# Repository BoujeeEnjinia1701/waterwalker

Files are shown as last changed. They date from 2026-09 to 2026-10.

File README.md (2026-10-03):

# WaterWalker

     

**Area:** Mobility and Logistics · **TRL:** 3 of 9 (proof of concept on paper) · **Value-engineering target:** USD 450 (estimated USD 492) · **Difficulty:** 3 of 5

Four-wheel walk-inside water carrier. The user walks between large wheels, rollator style, pushing through a hip bar, while a low padded cradle holds four 20 L jerrycans or two clay pots between the axles. Mounting points for a later push-sensing hub motor assist for sand and slopes.

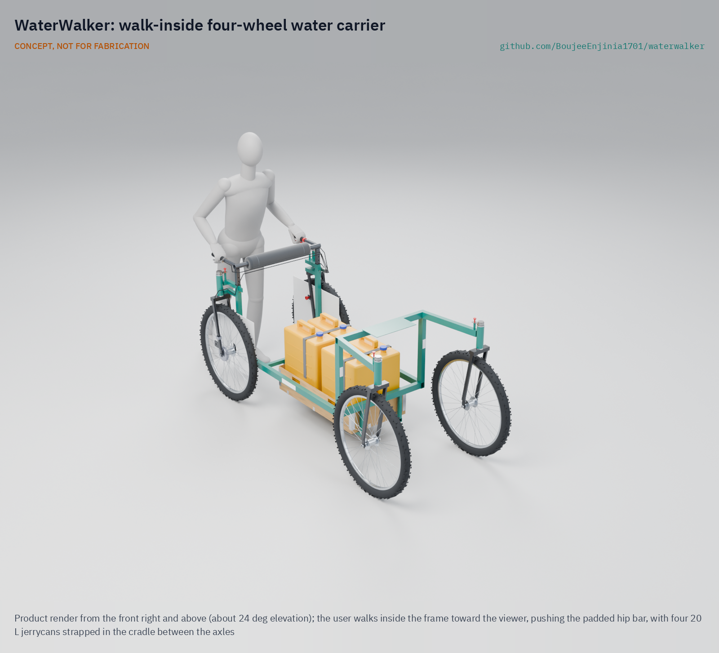
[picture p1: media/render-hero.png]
WaterWalker: walk-inside four-wheel water carrier, product render


[Exploded render](media/render-exploded.png) · [Detail render](media/render-detail.png) · [Interactive 3D model](media/viewer.html) · [Concept blueprint (PDF)](media/concept-blueprint.pdf) · [General arrangement WWK-DWG-001 (PDF)](cad/drawings/WWK-DWG-001.pdf) · [Sizing calculations WWK-CAL-001](docs/04-calcs/01-sizing.md) · [Prototype build plan WWK-BLD-001](docs/05-build-plan.md) · [Design decisions register WWK-DEC-001](docs/06-design-decisions.md) · [Review note](docs/REVIEW.md)

## Concept rationale

Wheels move water far better than heads do, but the rolling drums and carts already in use struggle on sand, on slopes and in tight turns, and a one-wheeled barrow asks for lifting and balance. WaterWalker puts the user inside a four-wheeled frame, the way a rollator does, so she walks normally, pushes with her hips as well as her hands, and steers by turning her body. The load rides low between the axles, where it cannot tip onto her or strain her neck, and the carrier works with the 20 L jerrycans households already own.

The design is open (CERN-OHL-S) and garage-buildable because the people who would use it live far from any factory. Everything is mild steel tube that a village welder can cut and repair, plus standard 26 in bicycle wheels, forks, cables and drum hubs sold in rural markets. An open design lets a local partner change the cradle, the width or the brakes after co-design sessions without asking anyone's permission, and lets repairs happen where the carrier breaks.

## Burning platform

According to the [WHO](https://www.who.int/news-room/fact-sheets/detail/drinking-water), 2.2 billion people still lacked safely managed drinking water services in 2022. Where water is not piped to the home, the carrying falls mostly on women: the 2023 WHO/UNICEF Joint Monitoring Programme report found that women and girls are primarily responsible for water collection in [7 out of 10 households](https://www.unicef.org/press-releases/women-and-girls-bear-brunt-water-and-sanitation-crisis-new-unicef-who-report) without water on the premises, and that 1.8 billion people live in such households.

The time lost is vast. [UNICEF estimates](https://www.unicef.org/press-releases/unicef-collecting-water-often-colossal-waste-time-women-and-girls) that women and girls spend 200 million hours every day collecting water, time taken from school, paid work and rest. Each head-carried trip moves a single 20 L container, about 20 kg.

## Where it could be used

### By industry

| Industry | Use |
| --- | --- |
| Rural water supply and WASH programmes | Last-mile carriage from boreholes, tap stands and water kiosks to homes, alongside new water points |
| Humanitarian response and refugee settlements | Moving water from distribution points to shelters over sandy or unpaved ground |
| Disaster response and civil protection | Carrying water from tanker trucks and supply points to homes while piped supply is cut |
| Smallholder farming | Watering seedlings and kitchen gardens, and moving produce or feed on footpaths |
| Schools and health posts without piped water | Bringing enough water for drinking, cooking and handwashing in fewer trips |

### By country or region

| Country or region | Why it matters there |
| --- | --- |
| Ethiopia | Only [49.6 % of people have basic water supply](https://www.unicef.org/ethiopia/water-sanitation-and-hygiene-wash), so many households walk to a water point on dirt paths in highlands and lowlands |
| Niger | [Only 56 % of the population has access to a source of drinking water](https://www.unicef.org/niger/water-sanitation-and-hygiene), so the rest must carry water from a source farther away |
| India | [Close to 54 % of rural women spend an estimated 35 minutes getting water every day](https://www.unicef.org/india/what-we-do/clean-drinking-water), equivalent to 27 days' lost wages a year, and less than 49 % of rural people use safely managed drinking water |
| Peru (hillside settlements of peri-urban Lima) | About 350 tanker trucks a day supply some 250,000 homes on the outskirts of Lima, and [a hillside household gets about 1,100 L of water a month](https://www.sciencedirect.com/science/article/pii/S2667010025003051) from tanks and trucks rather than household taps; on steep paths the brake, parking lock and slope limits matter |
| Japan (Noto Peninsula) | The January 2024 Noto earthquake [left up to 135,000 households without running water](https://www.japantimes.co.jp/news/2024/02/23/japan/society/noto-quake-sparks-water-debate/), and nearly 24,000 homes in Ishikawa Prefecture were still without water seven weeks later |

## What sparked the idea

The idea traces back to the rollator, the four-wheeled walking frame whose prototype the Swedish inventor Aina Wifalk designed in 1978 while working at an orthopedic clinic in Västerås, after polio had limited her own mobility ([Swedish Institute](https://sharingsweden.se/materials/the-invention-of-the-walker)). She never patented it, so that it could reach as many people as possible ([Svenskt UppfinnareMuseum](https://svensktuppfinnaremuseum.se/aina-wifalk/)), and today people of almost any age walk inside one without training. WaterWalker borrows that stance, walking inside a wheeled frame and pushing with the body, and her open approach, and applies both to the 20 L jerrycan instead of a person's own weight.

## Problem

Women and girls in rural sub-Saharan Africa and other low-income regions walk long distances carrying about 20 L of water on their heads per trip, which limits the quantity collected and causes neck and spine injuries. Design with, not for: requirements must come from co-design sessions and field trials with the intended users through a local partner.

## Concept

Four-wheel walk-inside water carrier. The user walks between large wheels, rollator style, pushing through a hip bar, while a low padded cradle holds four 20 L jerrycans or two clay pots between the axles. Mounting points for a later push-sensing hub motor assist for sand and slopes.

At TRL 3 the design is constructable: every part can be cut, welded, bought and fitted, and the build plan (WWK-BLD-001) shows how. Making it buildable added a cradle carrier, two-level rear head tube brackets, headsets and steering locks at all four forks and the fixings the concept lacked (WWK-DDR-003, accepted by Amish on 2026-10-02). His decisions of that day added a hold-to-release brake (let go of the bail under the left grip and a spring applies both rear brakes), a torque-arm tab on each rear fork for a two-motor assist kit, rated load and slope plates and hand holds in the cradle walls, which raised the empty mass to 40.3 kg. The sizing calculations (WWK-CAL-001 v0.4) show the carrier turns in 3.7 m and lifts containers only 364 mm, but four requirements are not met on paper: firm-path push (61.2 N against 60 N), loose sand (241 to 367 N against 150 N), the 10 % climb (182.6 N against 180 N) and empty mass (40.3 kg against 35 kg). The first prototype has no assist but keeps mounting points for a kit built to SwapCell interface v0.3, and parks with a positive lock pin. Value-engineering target: USD 450. Estimated cost of the constructable design: USD 492 (USD 42 over the target).

Full design precis: [docs/02-concept.md](docs/02-concept.md)

## Key components

- Welded mild steel tube frame with a cradle carrier and assist mounting points
- 26 in bicycle wheels in rigid forks on headsets, with puncture-resistant tires (4); front forks swivel and pin straight, rear forks are pinned straight
- Hip and hand push bar
- Padded plywood cradle for four jerrycans or two clay pots, bolted to two steel bearers
- Rear drum brakes with a lever latch for short stops, a hold-to-release brake and a parking lock pin
- Later, optional: two 250 W, 48 V hub motors with push-force sensor
- Later, optional: SwapCell pack (interface v0.3) in a class V1 receiver

The working bill of materials is in [bom/bom.csv](bom/bom.csv).

## Building the prototype

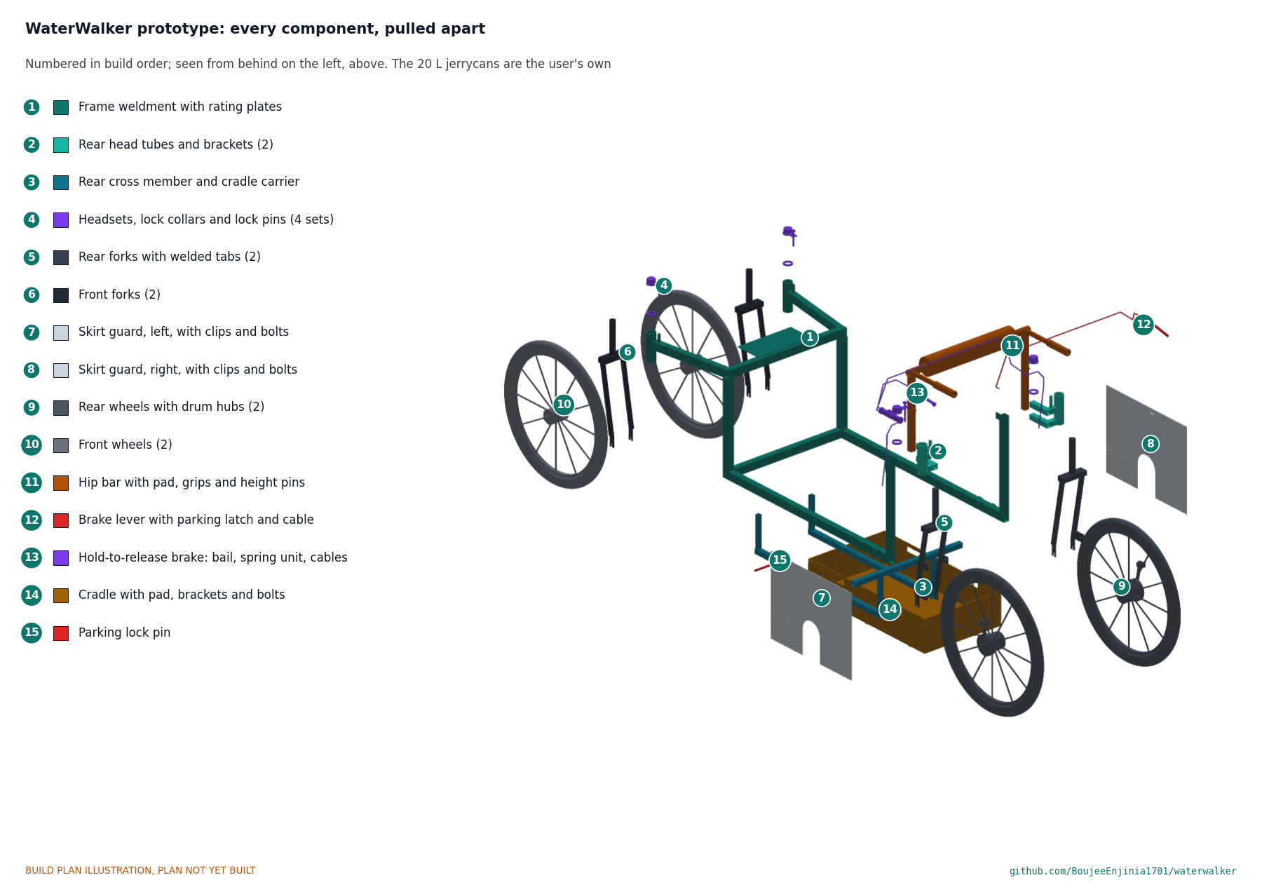
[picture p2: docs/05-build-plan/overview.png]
WaterWalker prototype: every component pulled apart and numbered in build order


The [prototype build plan](docs/05-build-plan.md) (WWK-BLD-001) takes a welder and a bicycle mechanic through the first prototype component by component, with a making sketch for each of the eight made components, close-ups of the joints and a picture for every assembly step. The frame is welded from mild steel tube on a flat floor; the forks, wheels, headsets and brakes are standard 26 in bicycle parts; the cradle is plywood bolted to two steel bearers. It is a plan, not yet built: building and testing to it is TRL 4 work, and the decisions, all made as of 2026-10-02, are in the [design decisions register](docs/06-design-decisions.md).

## Safety

> Rated load and slope limits must be marked on the frame. The brake must hold a full load on the steepest rated slope; on loose ground the rear tires may slide before the brake slips. The later assist kit contains a lithium battery pack: use a SwapCell pack with its BMS, cell-level protection and fuse, and charge it in a dock on a non-combustible surface.

## Repository layout

| Folder | Contents |
| --- | --- |
| `docs/` | Problem, concept, requirements, calculations and design decisions |
| `cad/src/` | build123d Python source, the source of truth for all geometry |
| `cad/step/`, `cad/stl/` | Exported models for FreeCAD, other CAD tools and printing |
| `cad/drawings/` | 2D sketches and dimensioned drawings |
| `bom/` | Bill of materials |
| `electronics/` | KiCad schematics and PCB layouts |
| `firmware/` | Microcontroller code |
| `media/` | Renders, perspectives and photos |
| `build-log/` | Dated prototyping notes |

## Documentation

Controlled documents follow the portfolio [documentation standard](.kit/STANDARDS.md). Each carries a document ID (WWK-PRC-001 for the precis), a version and a revision history. Branded PDFs are built with `python .kit/render.py` and attached to GitHub Releases when a document is tagged, for example `WWK-PRC-001/v1.0`.

## Credits

Designed by Amish Chadha. See [CONTRIBUTORS.md](CONTRIBUTORS.md) for roles. To cite this design, use [CITATION.cff](CITATION.cff) (GitHub shows it as "Cite this repository").

AI assistance (Claude) was used to accelerate concept renders, prototype documentation and first-pass sizing calculations. Design direction and all decisions are Amish Chadha's, recorded in this repository's decision records (`docs/decisions/`).

## Licenses

- **Hardware** (CAD, drawings, BOM, electronics): [CERN-OHL-S v2](LICENSE)
- **Software** (firmware, scripts, notebooks): [MIT](LICENSE-SOFTWARE)

A project of the [Design Molecule](https://designmolecule.com) lab.

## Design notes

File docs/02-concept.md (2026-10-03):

---
doc_id: WWK-PRC-001
title: WaterWalker design precis
project: WaterWalker
doc_type: Design precis
version: "0.7"
status: Draft
date: '2026-10-02'
author: Amish Chadha
license: CERN-OHL-S-2.0
revisions:
- version: "0.1"
  date: '2026-09-24'
  author: Amish Chadha
  change: Initial scaffold
- version: "0.2"
  date: '2026-09-24'
  author: Amish Chadha
  change: Populate to TRL 2 (architecture, first-order numbers, design choices, safety, media)
- version: "0.3"
  date: '2026-09-25'
  author: Amish Chadha
  change: TRL 3. Record Amish's decisions (WWK-DDR-001); numbers replaced with checked values from WWK-CAL-001; rear wheels in fixed forks, risers moved clear of the caster sweep, main tube upsized; assist mounting points to SwapCell interface v0.3; general arrangement WWK-DWG-001
- version: "0.4"
  date: '2026-09-25'
  author: Amish Chadha
  change: Recommendations accepted by Amish (DDR-002); 1.2 mm main-tube wall, thinner cradle and parking lock pin; numbers from WWK-CAL-001 v0.2; WWK-DWG-001 Rev P2
- version: "0.5"
  date: '2026-10-02'
  author: Amish Chadha
  change: Design made constructable (WWK-DDR-003); build plan WWK-BLD-001 and design decisions register WWK-DEC-001; numbers from WWK-CAL-001 v0.3; WWK-DWG-001 Rev P3; budget as a value-engineering target
- version: "0.6"
  date: '2026-10-02'
  author: Amish Chadha
  change: Dead-man brake, assist target and partner from Amish's decisions of 2026-10-02 (WWK-DEC-001)
- version: "0.7"
  date: '2026-10-02'
  author: Amish Chadha
  change: Decisions of 2026-10-02 carried into the design; hold-to-release brake (item 17) and two-motor assist mounting described; numbers from WWK-CAL-001 v0.4; WWK-DWG-001 Rev P4
---

# WaterWalker design precis

WaterWalker is a four-wheel water carrier that the user walks inside and pushes, like a rollator. Four 20 L jerrycans, or two 20 L clay pots, ride low in a padded cradle between the axles, so one trip carries up to 80 L, four times a head load, with no weight on the head or spine. The TRL 3 calculations (WWK-CAL-001 v0.4) show that the carrier turns in 3.7 m and needs about 24 to 61 N on firm ground, but it is heavier than estimated at TRL 2 (40.3 kg empty against a 35 kg target) and loose sand takes about 241 to 367 N, far above the 150 N target. Amish decided on 2026-09-25 to build the first prototype without assist but with mounting points for it, and later that day accepted the remaining recommendations (WWK-DDR-002): a lighter main tube and cradle and a positive parking lock pin. On 2026-10-02 the design was made constructable (WWK-DDR-003, accepted by Amish the same day), adding a cradle carrier, two-level rear head tube brackets, headsets and steering locks and the fixings the concept lacked; Amish's decisions of that day added a hold-to-release brake, a torque-arm tab on each rear fork for a two-motor assist kit, rating plates and cradle hand holds. The build plan (WWK-BLD-001) shows how to make it. Value-engineering target: USD 450. Estimated cost of the constructable design: USD 492 (USD 42 over the target). All numbers are paper estimates that co-design with the intended users must test (WWK-PRB-001).

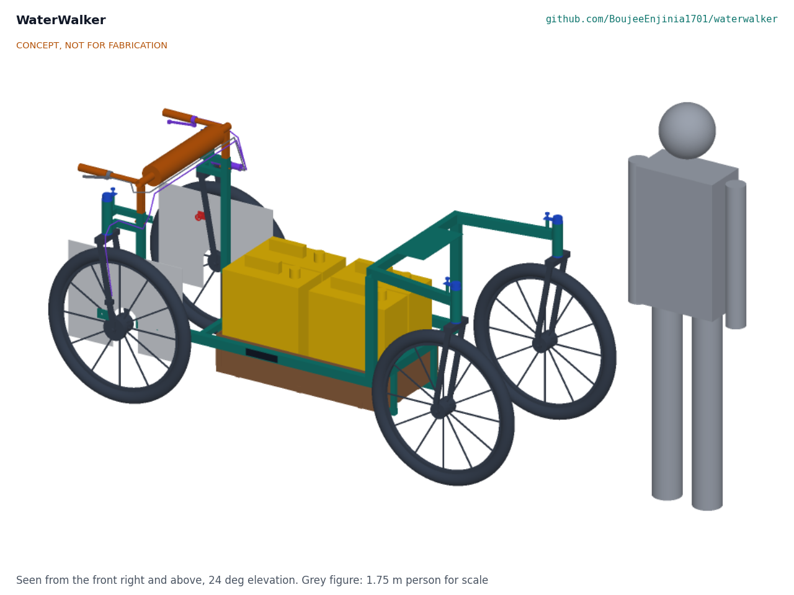
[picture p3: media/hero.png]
Hero render


*Figure 1. First prototype with four jerrycans, no assist fitted, beside a 1.75 m person.*

## How it works

1. **Walk in.** The frame is open at the rear. The user steps in between the rear wheels with no step-over and stands behind a padded hip bar, with a hand grip on each side, as in a rollator. Skirt guards sit between the user and the spokes of both rear wheels.
2. **Load.** Four 20 L jerrycans (or two clay pots) are lifted from the side, over a side rail at 364 mm, into a low padded cradle between the rear and front wheels.
3. **Push.** The user walks normally and pushes through the hip bar and grips. There is no pedalling, balancing or treadmill, so it works on slopes, in long skirts and for any walking user.
4. **Steer.** The rear wheels are fixed in rigid bicycle forks. The front wheels are on full-swivel caster forks, so the carrier follows the hip bar and turns about the user. The casters can be pinned straight for sand, cross-slopes and descents.
5. **Brake and park.** Drum brakes in both rear hubs are worked from a lever on the right grip, which has a latch for short stops. To park, the user pushes a lock pin from the walking space through tabs on both blades of the left rear fork and between the spokes, so the wheel cannot turn.
6. **Assist (later, optional).** The first prototype has mounting points but no assist. A later kit adds hub motors in the rear wheels (two are needed to meet R3 on the loosest sand; the kit's value-engineering target is set for two), powered by a removable SwapCell pack built to SwapCell interface v0.3, and gives thrust only while a sensor in the hip bar mount feels the user pushing, so the carrier never moves on its own.

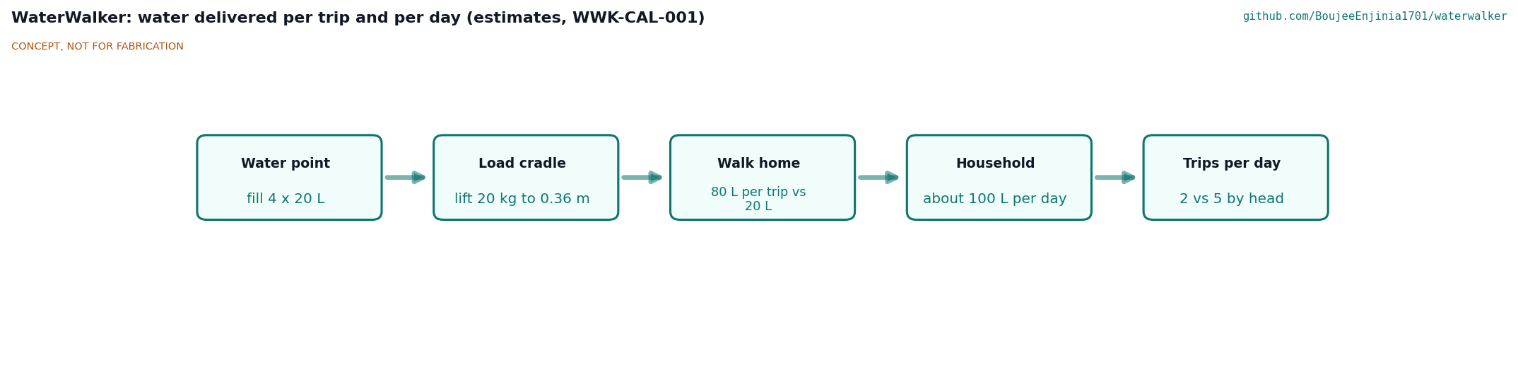
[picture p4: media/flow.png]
Water delivered per trip and per day


*Figure 2. Water delivered per trip and per day (estimates, WWK-CAL-001).*

## Main components

Item numbers match `bom/bom.csv`, the exploded view (Figure 3) and drawing WWK-DWG-001.

*Table 1. Main components.*

| # | Component | Choice | Notes |
| --- | --- | --- | --- |
| 1 | Frame | Mild steel: 40 x 30 x 1.2 mm rectangular tube for the side rails, front risers, caster arms and front cross members (wall decided 2026-09-25, WWK-DDR-002); 25 x 25 x 1.5 mm for the rear cross member, the two-level rear head tube brackets and the cradle bearers; 20 x 20 x 1.5 mm cradle hangers (WWK-DDR-003); 30 x 30 x 1.5 mm hip bar sleeves; welded | Open rear for walk-in entry; repairable by a local welder. Carries the assist mounting points: a receiver plate on the upper cross member, a torque-arm tab on each rear fork and a sensor tab on the right hip bar sleeve; a tab on the left hip bar sleeve carries the hold-to-release spring unit |
| 2 | Rear wheels (2) | 26 x 2.1 to 2.4 in wheels with 100 mm front-type drum-brake hubs, in rigid bicycle forks on headsets, pinned straight (item 16) | Wheel size decided 2026-09-25. Forks replace the TRL 2 stub axles (decided, WWK-DDR-001 item 9, WWK-DDR-002) |
| 3 | Front wheels (2) | 26 in wheels in rigid bicycle forks turned into caster forks, 60 mm trail, on headsets with a drop-pin swivel lock (item 16) | Full swivel, decided 2026-09-25 |
| 4 | Hip bar and hand grips | Padded steel bar on telescopic posts, 850 to 1,050 mm, rear-facing grips | Push through the hips as well as the hands; grip position and spacing are asked of users at the first co-design session |
| 5 | Cradle | Tray 780 x 430 mm: 6 mm plywood floor, 4 mm plywood walls 160 mm high, 2 mm rubber pad from used tires, straps and removable dividers, two 90 x 26 mm hand holds in each side wall | Four jerrycans 2 x 2, or two clay pots in line (decided 2026-09-25); thinner cradle decided 2026-09-25 (WWK-DDR-002) |
| 6 | Containers | The user's own 20 L jerrycans (four) | Shown for scale; not purchased |
| 7 | Brakes | Drum brakes in both rear hubs, one lever with a parking latch on the right grip; its cable runs along the front of the hip bar to the cable yoke in item 17 | Decided 2026-09-25; cable route 2026-10-02 |
| 8 | Skirt guards (2) | 3 mm HDPE panels between the inner fork blade and the spokes | Keep skirts, wraps and hands out of the spokes |
| 9 | Hub motors (optional, later, 2) | Two 250 W, 48 V geared front-type hub motors (100 mm) in 26 in rims, one in each rear wheel, each with a controller, torque arm and disc brake | Not in the first prototype; two-motor kit decided 2026-10-02 |
| 10 | Battery (optional, later) | SwapCell pack, interface v0.3 (13S2P, 46.8 V, about 450 Wh, 2.85 kg) | Priced once in the SwapCell BOM, excluded here |
| 11 | Push sensor and controller (optional, later) | 50 kg load cell in the hip bar mount, amplifier, microcontroller, brake cut-off | Motor runs only while the user pushes |
| 12 | Hardware and consumables | Bolts, axle nuts, paint, reflectors; two rated load and slope plates, on the outside of the right rail and the inside of the left rail | Plates modelled (decided 2026-10-02); fixings not modelled |
| 13 | SwapCell receiver (optional, later) | Vehicle receiver to latch class V1 with a 10 kΩ INTERLOCK coding resistor | Bolts to the item 1 receiver plate |
| 14 | Tires, tubes and liners (4 sets) | 26 x 2.1 to 2.4 in puncture-resistant tires, thorn-resistant tubes, liners | Not modelled separately; puncture protection kept (WWK-DDR-002) |
| 15 | Parking lock pin | 10 mm ball-lock pin with pull ring and lanyard, through tabs welded to the inner and outer blades of the left rear fork; passes through a hole in the left skirt guard and through the spokes | Decided 2026-09-25 (WWK-DDR-002); held at both ends (WWK-DDR-003); nothing projects beyond the axle nuts |
| 16 | Headset and steering lock sets (4) | 1 1/8 in external-cup headsets; a clamp collar with a lock plate on each steerer; an 8 mm pin into a guide on the frame | Added for construction (WWK-DDR-003) |
| 17 | Hold-to-release brake | A bail under the left grip; a spring unit (a 26 mm tube with a 390 N spring, a toggle and a cable yoke) on the left hip bar sleeve; cables to both rear drums | Decided 2026-10-02 (WWK-DEC-001); let go of the bail and the spring applies both rear brakes |

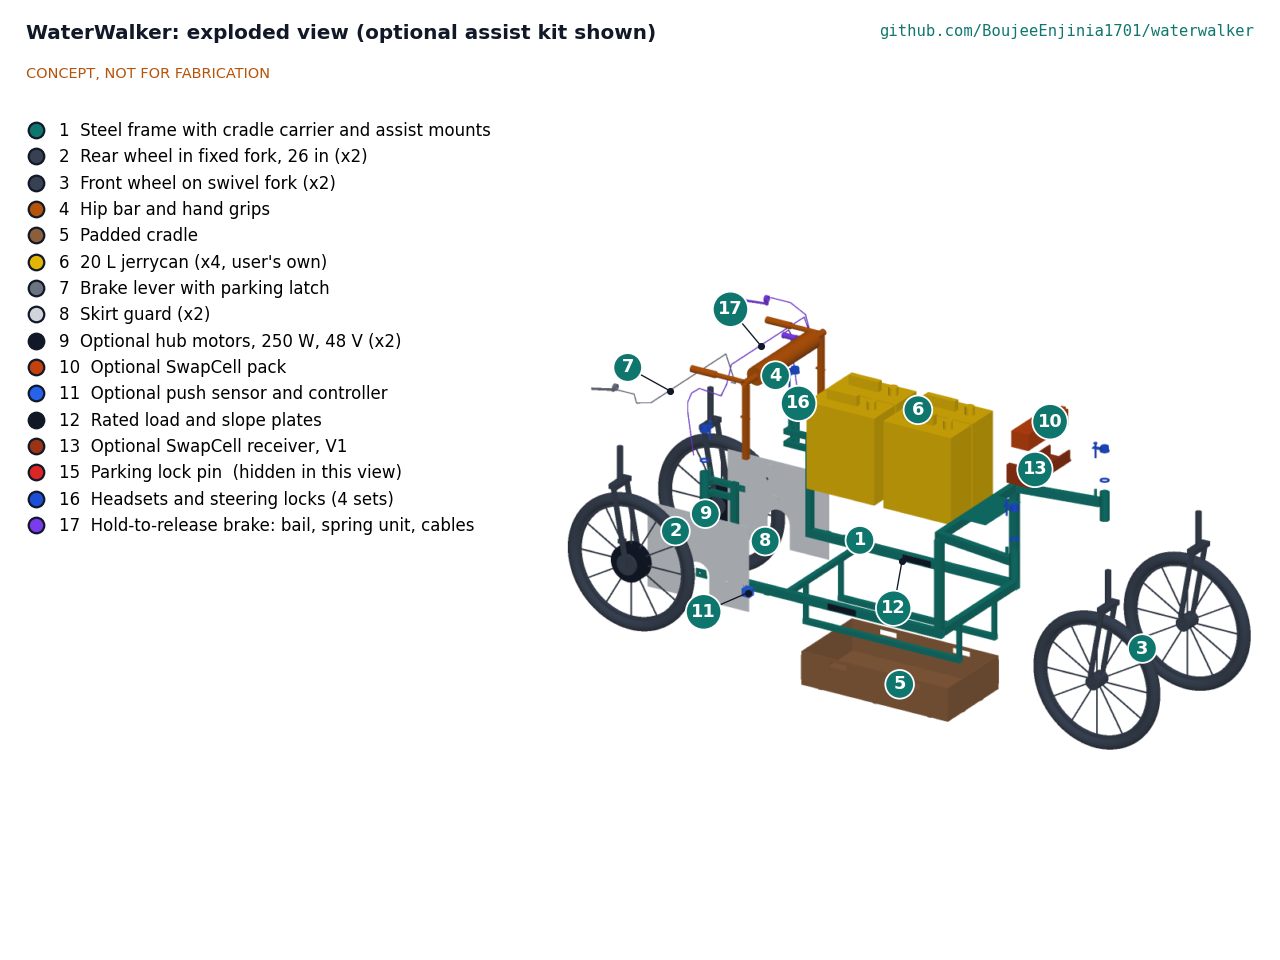
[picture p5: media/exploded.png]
Exploded view


*Figure 3. Exploded view with BOM callouts; the optional assist kit (items 9 to 11 and 13) is shown for its mounting points.*

The general arrangement is drawing WWK-DWG-001 Rev P4 (`cad/drawings/WWK-DWG-001.pdf`), generated from the parametric model `cad/src/model.py`. STEP files of the first prototype, the frame, the assist kit and the full assembly are in `cad/step/`.

## Assist mounting points and SwapCell interface v0.3

The first prototype carries mounting points so that a later assist kit bolts on without re-welding the frame (R13):

- **Pack receiver.** A 140 x 300 x 3 mm plate on the upper front cross member, about 835 mm above the ground and clear of the caster sweep, takes a SwapCell vehicle receiver built to latch class V1 (interface v0.3 item V: no release and no contact interruption under the UN 38.3 T3 vibration profile, 330 N preload through an over-centre lever). The pack lies across the carrier with its back and lid faces open to air, as the interface asks for vehicle mounts.
- **Wake without CAN.** The receiver fits the 10 kΩ INTERLOCK coding resistor (item W), which wakes the pack with no supply from the host. A simple assist controller without CAN then gets the pack's legacy discharge-only output (15 A limit); the two-motor assist needs at most about 7.8 A. A CAN controller may send the host heartbeat instead.
- **No charging on the carrier.** WaterWalker does not use the charge-while-discharging mode (item C); the pack is charged in a SwapCell dock.
- **Motors and sensor.** Both rear forks' 100 mm dropouts accept a front-type geared hub motor, and each rear fork carries a torque-arm tab welded behind its outer blade, 60 mm above the axle, so the two-motor kit bolts on (decided 2026-10-02). The motor wheels replace the drum-hub wheels, so the hold-to-release brake's yoke cables go to the motors' disc brakes, and the bail also works the controllers' brake cut-off. A tab on the right hip bar sleeve takes the push sensor. Value-engineering target for the assist prototype: USD 450. Estimated cost of the two-motor kit: USD 450 (on the target), pack excluded.

## Checked numbers

All values are from WWK-CAL-001 v0.4 and were checked against `docs/04-calcs/sizing.py`.

Assumptions: four 20 L jerrycans (84.4 kg with the cans); empty mass 40.3 kg from the mass roll-up of the model; loaded mass 124.7 kg (134.0 kg with the two-motor assist kit); g = 9.81 m/s²; rolling resistance coefficient 0.02 to 0.05 on firm dirt, and 0.197 to 0.300 on loose sand from a sinkage of 25 to 55 mm; one 250 W geared hub motor gives 40 N·m (120 N of thrust); walking at 1.0 m/s on firm ground and 0.6 m/s on sand.

*Table 2. Checked numbers against the requirements.*

| Quantity | Value | Requirement and status |
| --- | --- | --- |
| Water per trip | 80 L (four jerrycans) or 40 L (two clay pots, 12 mm spare length) | R1 at risk (pot size) |
| Push force, firm level path | 24.5 to 61.2 N | R2 (60 N) **not met** (by 1.2 N; accepted on paper) |
| Push force, loose sand, unassisted | 241 to 367 N | R3 (150 N) **not met** |
| Push force, loose sand, one or two motors (later) | 140 to 274 N (one); 20 to 154 N (two) | R3 needs two motors of about 41 N·m each |
| Push force, 10 % climb, firm | 146.0 to 182.6 N | R4 (180 N) **not met** (by 2.6 N; accepted on paper) |
| Hold-back force, 10 % descent | 61 to 97 N; about 72 N at the brake lever | R4 descent met on paper |
| Hold-to-release brake | 390 N spring; holds the loaded carrier with assist on up to 12 % if let go, stopping in about 2.6 m from 1.0 m/s on 10 %; squeeze 98 N, hold 24 N (estimate) | R10 at risk |
| Parking on 20 % | 258 N at the tires; lock pin (no hand force), or 192 N at the lever latch; tire friction 0.41 needed | R10 at risk |
| Turning circle | 3.66 m about the inner rear wheel | R5 met |
| Overall size | 898 mm wide, 2.2 m long | R6 at risk (2 mm margin) |
| Walk-in fit | 0 mm step-over; 610 mm clear walking width; hip bar 850 to 1,050 mm | R7 at risk (10 mm margin) |
| Container lift height | 364 mm over the side rail | R8 met |
| Side tip angle, loaded | 47 degrees | Static only |
| Empty mass | 40.3 kg (49.6 kg with the two-motor assist kit) | R9 **not met** (5.3 kg over) |
| Frame stress at 2.5 g | 129 MPa at the caster arm root; factor 1.82 on yield; rear brackets factor 2.4 when parked | Weld stress range 61 MPa, below the 71 MPa reference |
| Assist energy (later) | 170 Wh/km (two motors) on loose sand; 2.7 km per SwapCell pack | R13 not verifiable at TRL 3 |
| Parts cost | USD 492 first prototype; two-motor assist kit USD 450 more, pack excluded | R11 over the USD 450 value-engineering target by USD 42; assist kit on its USD 450 target |

### Comparison with head carrying

For a household of five using about 100 L per day, on a 3 km round trip (estimates):

*Table 3. Head carrying and WaterWalker.*

| | Head carrying | WaterWalker |
| --- | --- | --- |
| Water per trip | 20 L | 80 L |
| Trips per day for 100 L | 5 | 2 (1.25 rounded up) |
| Trips saved per day | | 3 |
| Walking time per day at 4 km/h | about 3.75 h | about 1.5 h, if walking speed is similar |
| Load on head and spine | about 20 kg | none; about 24 to 61 N push on firm ground |

The time saving shrinks on sandy routes, where walking is slower and the push force is high, and it does not include queueing and filling time at the water point, which the carrier does not change.

## Key design choices

Items 1 to 6 were decided by Amish on 2026-09-25: go with recommendation (WWK-DDR-001). Items 7 to 10 came out of the TRL 3 calculations and were decided by Amish later on 2026-09-25: go with recommendation (WWK-DDR-002).

1. **Wheel size (decided).** 26 x 2.1 to 2.4 in all round, for sand performance, one spare tire size and wide availability in rural markets. WWK-CAL-001 shows that no practical tire width brings the sand push force down to 150 N; even 4 in fat-bike tires leave 177 to 269 N.
2. **No assist in the first prototype (decided).** The first prototype has mounting points for a later assist kit; the USD 450 value-engineering target covers exactly that. The later kit needs two hub motors, not one, to meet R3 on the loosest sand. The value-engineering target for that assist prototype is about USD 450 for the two-motor kit, with the shared SwapCell pack counted separately (decided by Amish, 2026-10-02, WWK-DEC-001).
3. **Steering (decided).** Full-swivel lockable front casters.
4. **User position (decided).** Between the rear wheels.
5. **Cradle (decided).** Four jerrycans or two clay pots, until co-design shows how often pots are used.
6. **Brakes (decided).** Drum brakes in both rear hubs with a parking latch. A hold-to-release (dead-man) brake is fitted on the first prototype: a spring applies both drums unless the user holds a bail on the grips (decided by Amish, 2026-10-02, WWK-DEC-001); users are asked about it in co-design.
7. **Rear wheels in fixed forks (decided).** A cantilevered M10 axle is overstressed (about 459 MPa at 2.5 g); a fixed rigid fork holds it on both sides (about 86 MPa). This needs 100 mm front-type drum hubs at the rear and a 770 mm track.
8. **Risers clear of the caster sweep (decided).** Risers at x = 1,150 mm, wheelbase 1,530 mm, cradle 780 mm long.
9. **Main tube 40 x 30 mm (decided).** The TRL 2 section had a yield factor of only 1.45 at the caster arm root. The wall is 1.2 mm under item 10, which gives a factor of 1.77.
10. **Mass and parking (decided).** The thinner cradle and the 1.2 mm main-tube wall are applied (empty mass 40.8 to 37.4 kg), puncture protection is kept, and R9 is to be revisited with users in co-design. A positive lock pin is added for parking, with the lever latch kept for short stops. See WWK-DDR-001 items 12 and 13 and WWK-DDR-002.
11. **Design for construction (made and accepted 2026-10-02).** The concept's parts were made buildable without changing what the carrier does: the cradle rests on two bearers hung from the cross members, each rear head tube is held by two brackets 60 mm behind the axle, all four forks run in headsets with lock collars and pins, the caster arms leave directly over the risers, and the guards, lock pin, brake arms and cradle have real fixings (WWK-DDR-003). The empty mass rose to 39.6 kg (40.3 kg with the decisions of 2026-10-02 carried in); Amish accepted the changes on 2026-10-02 (WWK-DEC-001). The build plan is WWK-BLD-001.

## Safety

> **Safety:** A loaded WaterWalker has a mass of about 125 kg (134 kg with the assist kit). On a 10 % slope it pulls downhill with about 61 to 97 N more than rolling resistance absorbs. Rated load and slope limits are marked on two plates on the frame, and the parking brake must hold a full load on the steepest rated slope. Parked facing downhill on a 20 % grade, the rear tires need a friction coefficient of about 0.41, which loose gravel or sand may not give.

- **Runaway on slopes.** If the user trips or lets go on a descent, the carrier rolls away. Mitigations: service brake on a grip, parking latch, a positive lock pin (decided, WWK-DDR-002), casters pinned straight on descents, and a hold-to-release (dead-man) brake: a spring applies both rear drums unless the user holds the bail under the left grip (decided 2026-10-02, BOM item 17). On paper the spring alone holds the loaded carrier on up to 12 % but not on 20 %, so the latch and lock pin stay the parking brakes, and the brake is tested before the first loaded descent. A wrist tether is an option to test in co-design.
- **Brakes.** The paper sizing needs about 192 N at the lever to set the parking latch on 20 %, which many users cannot give; the lock pin is for parking. The pin must be pulled before moving off, and it loads the spokes sideways, which needs a test. Sand and water in rim brakes are the main reason for choosing drums.
- **Tipping.** The low cradle gives a static side tip angle of about 47 degrees, but a wheel dropping into a rut or ditch on a cross-slope can still tip the carrier. Containers must be strapped so the load cannot shift. Do not carry children or people in the cradle.
- **Pinch and entanglement points.** Spokes, caster forks, the 400 mm caster sweep and brake levers can catch skirts, wraps, fingers and children's hands. Skirt guards cover the rear spokes. Caster swivel zones must be kept clear of feet and marked, and the hip bar telescopic joints must not pinch.
- **Structure.** The frame is sized for 2.5 g with a factor of about 1.8 on yield with the 1.2 mm wall. With the cradle hung from the cross members (WWK-DDR-003) the weld stress range in the rail is 61 MPa, below the 71 MPa reference for a typical fillet weld, but fatigue cracking on rough paths is still possible and only a test can confirm the life. The tabs welded to the steel rear forks must be welded with care and inspected, and the rear cross member and caster arm welds are inspected at every service until the TRL 4 fatigue test (decided 2026-10-02).
- **Lifting.** Lifting 20 kg to 364 mm is far safer than lifting to head height, but containers should be filled in place where possible and loaded from the side with a straight back. The empty carrier (about 40 kg) is a two-person lift over steps and ditches.
- **Lithium battery (later assist only).** The SwapCell pack has a battery management system, cell-level protection and a fuse (SwapCell interface v0.3). On the carrier it must sit in a latch class V1 receiver, be protected from water and sand while leaving its back and lid faces open to air, and never be charged if damaged or swollen. Charging is in a SwapCell dock on a non-combustible surface away from sleeping areas. The motor must run only while the push sensor detects the user pushing, with a hard cut-off when the brake lever is pulled or the bail is let go.
- **Single-sided drive (later assist only).** One hub motor makes a 46 N·m yaw moment, which is why the assist kit has two motors. If only one is ever run, the casters must be locked straight.

## Open questions

- Confirm rolling resistance and sinkage in loose sand on the users' routes; WWK-CAL-001 uses an assumed 25 to 55 mm.
- Confirm the sustained push force limits with the intended users, including girls and older women; R2 and R4 now miss by only 1.2 N and 2.6 N.
- Can a geared hub motor deliver about 40 N·m at 17 to 29 rpm without overheating? At 40 % efficiency each motor makes about 110 W of heat on sand.
- Are 100 mm front-type drum hubs sold and serviced in the first region's markets (R12)?
- Decide how often clay pots are used and their real diameter; the cradle fits two pots of up to about 384 mm.
- Approach the first partner for co-design through the Helpful Engineering network, with Kitui County, Kenya, as the first candidate region (decided by Amish, 2026-10-02, WWK-DEC-001).

Concept media: [blueprint sheet](../media/concept-blueprint.pdf), [interactive 3D model](../media/viewer.html).

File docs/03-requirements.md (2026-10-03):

---
doc_id: WWK-REQ-001
title: WaterWalker requirements
project: WaterWalker
doc_type: Requirements
version: "0.7"
status: Draft
date: '2026-10-02'
author: Amish Chadha
license: CERN-OHL-S-2.0
revisions:
- version: "0.1"
  date: '2026-09-24'
  author: Amish Chadha
  change: Initial scaffold
- version: "0.2"
  date: '2026-09-24'
  author: Amish Chadha
  change: First measurable requirements for TRL 2
- version: "0.3"
  date: '2026-09-25'
  author: Amish Chadha
  change: TRL 3. Record Amish's decisions (WWK-DDR-001); redefine R1 (four jerrycans or two clay pots) and R11 (budget covers the unassisted first prototype with mounting points); add R13 (assist-ready to SwapCell interface v0.3); add status from WWK-CAL-001
- version: "0.4"
  date: '2026-09-25'
  author: Amish Chadha
  change: Recommendations accepted by Amish (DDR-002); R10 restated for the positive lock pin; status updated from WWK-CAL-001 v0.2
- version: "0.5"
  date: '2026-10-02'
  author: Amish Chadha
  change: Status from WWK-CAL-001 v0.3 for the constructable design (WWK-DDR-003); R11 reported against the value-engineering target
- version: "0.6"
  date: '2026-10-02'
  author: Amish Chadha
  change: R2 and R4 notes record Amish's decision of 2026-10-02 to accept them as not met on paper (WWK-DEC-001); no status changed
- version: "0.7"
  date: '2026-10-02'
  author: Amish Chadha
  change: Values from WWK-CAL-001 v0.4 after the decisions of 2026-10-02 were carried into the design (hold-to-release brake, two-motor assist kit, torque-arm tabs on both rear forks); R10 and R13 wording for the new brake and tabs; no status changed
---

# WaterWalker requirements

Four of the thirteen requirements are not met on paper (R2, R3, R4 and R9), five are at risk and two are met, according to WWK-CAL-001 v0.4; R11 is over its value-engineering target and R13 cannot be verified at TRL 3. Targets are still desk proposals and must be revised from co-design sessions with the intended users (WWK-PRB-001) before the design is frozen. On 2026-09-25 Amish decided to build the first prototype without assist but with mounting points, keep the USD 450 figure, and carry four jerrycans or two clay pots (WWK-DDR-001); R1 and R11 were redefined to match, and R13 is new. Later the same day Amish accepted the remaining recommendations (WWK-DDR-002), including a positive parking lock pin, for which R10 is restated. On 2026-10-02 the design was made constructable (WWK-DDR-003): the parts added for construction made the carrier 2.2 kg heavier, which moved R2 and R4 from at risk to not met. Amish accepted the changes and R2 and R4 as not met on paper the same day, and decided on a hold-to-release brake and a two-motor assist kit; carried into the design, these add 0.7 kg, so R2 and R4 are now short by 1.2 N and 2.6 N (WWK-DEC-001). On 2026-10-01 Amish set budgets as value-engineering targets, so R11 is reported against its target rather than as met or not met.

*Table 1. Requirements and status at TRL 3 (WWK-CAL-001).*

| ID | Requirement | Target | Verification (TRL 3 or later) | Status at TRL 3 |
| --- | --- | --- | --- | --- |
| R1 | Carry a household's water in one trip | 80 L of water in four 20 L jerrycans, or 40 L in two 20 L clay pots; rated gross payload 90 kg including containers (redefined 2026-09-25, WWK-DDR-001) | Cradle layout in the parametric model; later load test | At risk: two 380 mm pots fit with 12 mm to spare |
| R2 | Easy to push on firm ground | Sustained push force 60 N or less at rated load on a firm, level dirt path | Rolling resistance calculation; later force gauge on a field path | **Not met**: 24.5 to 61.2 N (by 1.2 N); accepted on paper by Amish on 2026-10-02, with the limit confirmed with users in co-design (WWK-DEC-001) |
| R3 | Usable on loose sand | Sustained push force 150 N or less at rated load on loose sand, with assist if fitted | Calculation from sinkage and rolling resistance; later field test | **Not met**: 241 to 367 N (no assist on the first prototype); 20 to 154 N with the two-motor kit |
| R4 | Climb and descend slopes | Climb a 10 % grade on firm ground with a push force of 180 N or less for up to 100 m; descend a 10 % grade under control with the service brake | Force calculation; brake sizing | **Not met**: 182.6 N at the rough end (by 2.6 N); descent met on paper, and the hold-to-release brake alone holds the carrier on up to 12 % if the user lets go; accepted on paper by Amish on 2026-10-02, with the limit confirmed with users in co-design (WWK-DEC-001) |
| R5 | Turn without lifting | 180 degree turn within a 4.0 m diameter circle without lifting or skidding a wheel; reverse by pulling back | Geometry of the parametric model | Met: 3.66 m |
| R6 | Fit narrow paths and gates | Overall width 900 mm or less | Parametric model | At risk: 898 mm |
| R7 | Walk-in fit for all users | No step-over at the rear entry (50 mm or less); clear walking width 600 mm or more; hip bar height adjustable 850 to 1,050 mm; skirt guards on both rear wheels | Parametric model; later co-design fitting sessions | At risk: walking width 610 mm |
| R8 | Easy loading | Containers lifted no higher than 450 mm above the ground; loadable from either side without removing parts | Parametric model | Met: 364 mm |
| R9 | Light enough to handle empty | Empty mass 35 kg or less without assist, 42 kg or less with assist | Mass roll-up from the parametric model | **Not met**: 40.3 kg (49.6 kg with the two-motor kit); to be revisited with users in co-design (WWK-DDR-002) |
| R10 | Safe braking and parking | Service brake on both rear wheels operable while walking; a positive parking lock (lock pin through a rear wheel) that needs no sustained hand force holds the rated gross mass on a 20 % grade; the lever latch serves short stops (restated 2026-09-25, WWK-DDR-002); a hold-to-release brake applies both rear brakes when the user lets go of the bail (decided 2026-10-02, WWK-DEC-001) | Brake force calculation; later parking and descent tests | At risk: lock pin held at both ends; tire friction 0.41 needed; latch 192 N; hold-to-release brake squeeze 98 N, hold 24 N (estimate) |
| R11 | Affordable first prototype | Parts for the first prototype, without assist and with assist mounting points, against a value-engineering target of USD 450 (`project.yaml` budget, kept 2026-09-25; a hypothetical control target, not a limit, 2026-10-01). The budget excludes the optional assist kit, which is a later second prototype, and the SwapCell pack, which is priced once in the SwapCell BOM (redefined 2026-09-25, WWK-DDR-001) | Priced BOM | Over the target by USD 42: USD 492 |
| R12 | Repairable in a rural market | All wear parts (tires, tubes, spokes, bearings, cables, brake shoes) are standard 26 in bicycle parts; mild steel frame repairable by a local welder; only common hand and bicycle tools needed | Design review of the BOM; later review with a local mechanic | At risk: 100 mm drum hubs are less common than rim-brake hubs |
| R13 | Assist-ready (new 2026-09-25) | The first prototype carries mounting points for a later assist kit built to SwapCell interface v0.3: a plate for a latch class V1 vehicle receiver above the tires, with the pack's back and lid faces open to air; rear dropouts that accept a 100 mm hub motor, with a torque-arm tab on each rear fork for the two-motor kit (2026-10-02); a boss for a push sensor at the hip bar. The receiver fits a 10 kΩ INTERLOCK coding resistor (item W), and the assist draws no more than the 15 A legacy-mode limit | Parametric model; later latch class V1 test | Not verifiable at TRL 3: geometry present, 7.8 A peak |

## Assumptions

- A 20 L jerrycan weighs about 1.1 kg empty and measures about 360 x 175 x 430 mm. A 20 L clay pot is assumed to be about 380 mm in diameter and 5 to 8 kg empty.
- Sustained push forces are set with reference to published manual-handling guidance, which suggests roughly 100 to 150 N for sustained pushing by women over long distances and more for short efforts. The limits must be confirmed with the users, including girls and older women.
- A household of five uses about 100 L per day (about 20 L per person).
- The first prototype has no assist (WWK-DDR-001), so R3 cannot be met by it; R3 stays as the target for the later assist prototype, which needs about 244 N of thrust (two hub motors, about 41 N·m each) to meet it on the loosest sand (WWK-CAL-001 v0.4). Its value-engineering target is about USD 450 for the two-motor kit, pack excluded (Amish, 2026-10-02).
- R5 allows a larger circle than a compact rollator because the concept needs a long wheelbase to keep the swivelling front wheels clear of the cradle (WWK-PRC-001). A three-point turn is expected on paths narrower than 4 m.

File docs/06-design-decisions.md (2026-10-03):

---
doc_id: WWK-DEC-001
title: WaterWalker design decisions register
project: WaterWalker
doc_type: Design decisions register
version: "0.3"
status: Draft
date: '2026-10-02'
author: Amish Chadha
license: CERN-OHL-S-2.0
revisions:
- version: "0.1"
  date: '2026-10-02'
  author: Amish Chadha
  change: Register opened with the design made constructable (WWK-DDR-003); budget treated as a value-engineering target
- version: "0.2"
  date: '2026-10-02'
  author: Amish Chadha
  change: Amish approved the recommendations for open items 1 to 8 on 2026-10-02 (WWK-DDR-003 accepted with A1 and A2, Kitui County as first candidate region, dead-man brake, two-motor assist target, weld fatigue, appearance choices); moved to decisions made
- version: "0.3"
  date: '2026-10-02'
  author: Amish Chadha
  change: Decisions carried into the design; value engineering restated for the hold-to-release brake (USD 492) and the two-motor assist kit (USD 450); item 4 to confirm now names the cable yoke
---

# WaterWalker design decisions register

Every design decision still to be made, and every decision made, in one place. Each decision is argued in full in its decision record under `docs/decisions/`; this register is the index Amish works from. The build plan (`docs/05-build-plan.md`, WWK-BLD-001) describes the design as it stands and does not list open decisions.

## Open decisions

None. All open decisions were decided on 2026-10-02.

## To confirm when parts are bought

*Table 2. Items to confirm.*

| # | What to confirm | Why it matters | Source |
| --- | --- | --- | --- |
| 1 | The rigid 26 in forks: steel, 1 1/8 in steerer at least 170 mm above the crown, 100 mm dropouts, and their offset (the model uses 60 mm) | The offset is the caster trail and sets where the rear head tubes sit; steel blades take the welded tabs | WWK-DDR-003, P3, P13 |
| 2 | External-cup (EC34) headsets fit the 34 mm head tube bore | The head tubes are cut and reamed to suit | WWK-DDR-003, P7 |
| 3 | 100 mm front-type drum hubs are sold and serviced in the region, and their reaction arm and clip fit the fork blade | R12; the reaction arm must lie along the blade | WWK-REQ-001 R12; WWK-DDR-003, P9 |
| 4 | The brake lever with parking latch and the bail lever clamp on 22.2 mm tube, and a cable yoke that lets either input pull both outputs fits inside the 26 mm spring unit with a spring of about 390 N | The grip tubes and the spring unit are sized for them | WWK-DDR-003, P8; WWK-CAL-001 v0.4 section 6 |
| 5 | A 10 mm ball-lock pin with about 140 mm usable length | It must reach the outer tab and stay inside the axle nuts | WWK-DDR-003, P10 |
| 6 | The tires chosen (2.1 to 2.4 in) clear the fork crown by 25 mm or more | The model has 33 mm with 2.1 in tires | `cad/src/model.py` |
| 7 | The real diameter of the clay pots users carry | Two 380 mm pots fit with 12 mm to spare (R1) | WWK-REQ-001 R1 |

## Value engineering

Value-engineering target: USD 450. Estimated cost of the constructable design: USD 492 (USD 42 over the target). This is the first prototype without assist and with mounting points; the target is a hypothetical control target, not a limit. For the later assist prototype: value-engineering target: USD 450. Estimated cost of the two-motor kit: USD 450 (on the target), pack excluded. Main cost drivers and savings worth trying:

- The largest lines are the wheels and forks (USD 168 for four built wheels in forks, BOM lines 2 and 3), the tires, tubes and liners (USD 96, line 14), the frame weldment (USD 62, line 1), the four headset and steering lock sets (USD 32, line 16) and the hold-to-release brake (USD 30, line 17).
- Making the design constructable added USD 36: the four headset and lock sets (line 16, USD 32, of which USD 12 was in line 3 before), the cradle carrier and second rear brackets (line 1, USD 6), cradle brackets and bolts (line 5, USD 5), guard clips (line 8, USD 2), the second lock pin tab (line 15, USD 1) and fixings (line 12, USD 2).
- The decisions of 2026-10-02 added USD 30: the hold-to-release brake (line 17, USD 30) less the splitter it replaces (line 7, USD 4), the second torque-arm tab and the spring unit tab (line 1, USD 1) and two rating plates (line 12, USD 3).
- Savings worth trying: plain bushed rear head tubes held by a cross bolt instead of rear headsets (about USD 10, but two kinds of head tube to make); buying the four wheels as one built set (often USD 10 to 20 less than four singles); tire liners only on the rear wheels (USD 8), if co-design shows punctures are rare on the routes.

## Decisions made

*Table 3. Decisions made.*

| Date | Decision | Decided by | Record |
| --- | --- | --- | --- |
| 2026-09-25 | TRL 2 review items 1 to 6: 26 in wheels; no assist in the first prototype, with mounting points; full-swivel lockable casters; user between the rear wheels; four jerrycans or two clay pots; rear drum brakes with a parking latch | Amish: "proceed with all of your recommendations across all batches. Make sure we don't proceed to TRL 4 on any of them." | WWK-DDR-001 |
| 2026-09-25 | Cross-cutting: assist mounting points to SwapCell interface v0.3 (items W and V); SwapCell pack priced once in the SwapCell BOM; co-design partners picked per area later | Amish, same instruction | WWK-DDR-001 |
| 2026-09-25 | Items 9 to 13: rear wheels in fixed forks with 100 mm drum hubs and a 770 mm track; risers at 1,150 mm and a 1,530 mm wheelbase; 40 x 30 mm main tube; 1.2 mm main wall and thinner cradle, puncture protection kept, R9 revisited with users; positive parking lock pin | Amish: "i accept all your recommendations, go with them across all repos." | WWK-DDR-002 |
| 2026-09-30 | Build plan format with pictures for every component and step; open decisions kept out of the build plan and in this register; the design made physically buildable as the pictures are drawn | Amish: "fix the design assumptions to match and be physically feasible as you draw the illustrations" and "don't log outstanding decisions in this build plan" | WWK-DDR-003 (changes open for review, Table 1 item 1) |
| 2026-10-01 | `budget_usd` is a value-engineering target, not a limit | Amish: "the budgets are a hypothethical control target to ensure we are thinking along a value engineering lens" | `.kit/STANDARDS.md` section 18 |
| 2026-10-02 | Design for construction accepted: the changes P1 to P16 of WWK-DDR-003, as made | Amish: "APPROVED: The open decisions from the last wave (TremorTrace to ZeerBox) came in after the review and aren't on the page either." | WWK-DDR-003, Table 1 |
| 2026-10-02 | R2 and R4: accepted as not met on paper by 0.8 N and 1.5 N; the puncture protection chosen on 2026-09-25 is kept, and the push limits are confirmed with users in co-design | Amish: "APPROVED: The open decisions from the last wave (TremorTrace to ZeerBox) came in after the review and aren't on the page either." | WWK-DDR-003, A1 |
| 2026-10-02 | Ground clearance: 125 mm under the cradle carrier accepted; a clearance figure is added to the requirements after the first route survey | Amish: "APPROVED: The open decisions from the last wave (TremorTrace to ZeerBox) came in after the review and aren't on the page either." | WWK-DDR-003, A2 |
| 2026-10-02 | First co-design partner and region: the Helpful Engineering network is the route to a first partner, a university engineering department or water and sanitation NGO in semi-arid eastern Kenya, where water is carried along sandy routes and dry riverbeds; Kitui County is the first candidate region | Amish: "APPROVED: The open decisions from the last wave (TremorTrace to ZeerBox) came in after the review and aren't on the page either." | WWK-DDR-001 item 7 |
| 2026-10-02 | Dead-man brake: a hold-to-release (dead-man) brake is fitted on the first prototype: a spring applies both rear drum brakes unless the user holds a bail on the grips, kept alongside the service lever, parking latch and lock pin; users are asked about it in co-design, and it is dropped only if descent trials and users show the latch and pin are reliably used | Amish: "APPROVED: The open decisions from the last wave (TremorTrace to ZeerBox) came in after the review and aren't on the page either." | WWK-DDR-001 item 8 |
| 2026-10-02 | Value-engineering target for the later assist prototype: about USD 450 for the two-motor assist kit (two rear hub motors with their controller and push sensor), with the shared SwapCell pack counted separately; the USD 260 one-motor kit is used only if sand trials show one motor meets R3 | Amish: "APPROVED: The open decisions from the last wave (TremorTrace to ZeerBox) came in after the review and aren't on the page either." | WWK-DDR-002 item 14 |
| 2026-10-02 | Weld fatigue: the frame joints are accepted without gussets until a fatigue test at TRL 4 (61 MPa stress range in the rail, below the 71 MPa reference), and the rear cross member and caster arm welds are inspected at every service until then | Amish: "APPROVED: The open decisions from the last wave (TremorTrace to ZeerBox) came in after the review and aren't on the page either." | `docs/REVIEW.md` (2026-09-25); WWK-CAL-001 v0.3 section 7 |
| 2026-10-02 | Appearance-model choices: the left brake cable along the hip bar, the hand holds in the cradle side walls and the rated load and slope plates are adopted; grip position and spacing are asked of users at the first co-design session | Amish: "APPROVED: The open decisions from the last wave (TremorTrace to ZeerBox) came in after the review and aren't on the page either." | `docs/REVIEW.md` (2026-09-26), items 1 to 5 |

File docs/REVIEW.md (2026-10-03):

# Review note: WaterWalker

## Session 2026-09-24: /populate to a strong TRL 2

### What was done

- `docs/01-problem.md` (WWK-PRB-001 v0.2): co-design placed first with the existing checklist kept and first-session questions added; the problem, users and context, constraints (terrain, sand, slopes, narrow paths, local repair), prior work (head carrying, Hippo Roller, Wello WaterWheel, loaded bicycles, carts, Lopifit, rollators) and out of scope.
- `docs/03-requirements.md` (WWK-REQ-001 v0.2): 12 measurable requirements (R1 to R12) with targets, planned verification and assumptions.
- `docs/02-concept.md` (WWK-PRC-001 v0.2): how it works, components numbered to match the exploded view and BOM, first-order numbers with assumptions, comparison with head carrying, six proposed design choices, safety and open questions.
- `cad/src/concept_media.py`: massing model (steel frame open at the rear, four 26 in wheels with full-swivel front casters, hip bar and grips, low padded cradle with four jerrycans, drum brakes, skirt guards, and optional hub motor, SwapCell pack and push sensor) with the 1.75 m scale figure.
- `media/`: hero, blueprint sheet (PNG, SVG and PDF), exploded view with BOM callouts, water-per-trip flow diagram (estimates), `model.glb` and `viewer.html`. No cutaway, because the inside does not matter for this concept.
- `bom/bom.csv`: 12 lines with indicative prices, numbered to match the exploded view; `bom/bom-notes.md`.
- `README.md`: hero image and links line added.
- `docs/pdf/`: branded PDFs of the three controlled documents.

### Key results (estimates, to be checked at TRL 3)

| Quantity | Estimate | Requirement |
| --- | --- | --- |
| Water per trip | 80 L (four jerrycans), four times a head load | R1 met for jerrycans only |
| Push force, firm level path | about 25 to 55 N | R2 (60 N) met |
| Push force, loose sand | about 225 to 340 N unassisted; about 120 to 240 N with assist | R3 (150 N) **not met** |
| Push force, 10 % climb | about 135 to 170 N unassisted; about 25 to 60 N with assist | R4 (180 N) met, thin margin |
| Turning circle | about 3.8 m | R5 (4.0 m) met, thin margin |
| Size | about 860 mm wide, 2.2 m long | R6 met |
| Empty mass | about 31 kg (38 kg with assist) | R9 met |
| Parts cost | about $300 without assist; about $600 with assist | R11 met without assist, **not met** with assist |
| Trips for 100 L per day | 2, versus 5 by head (3 trips saved) | |

Requirements not met:

- **R3 (sand).** Unassisted push force on loose sand is about 1.5 to 2.3 times the 150 N target. A single 250 W hub motor only brings the firmer end of the range within target.
- **R1 (clay pots).** The 430 mm cradle holds four jerrycans but only two 20 L clay pots. Four pots would make the carrier about 1.1 m wide and break R6.
- **R11 with assist.** The assisted version is about $600, over the $450 budget.

### Proposed, awaiting Amish

Status update (2026-09-25): items 1 to 6 are Decided by Amish, 2026-09-25: go with recommendation (WWK-DDR-001). Item 7 has no recommendation and remains Proposed, awaiting Amish.

1. Wheel size: 26 x 2.1 to 2.4 in all round. Alternatives: 20 in, 26 in rear with 20 in front, 28 in.
2. First prototype without assist, with mounting points for it. Keep the $450 budget. No budget change is proposed.
3. Steering: full-swivel lockable front casters. This choice is why the wheelbase is long (1.52 m).
4. User position between the rear wheels rather than behind the rear axle.
5. Cradle for four jerrycans or two clay pots until co-design shows how often pots are used. If accepted, the pitch in `project.yaml` ("four 20 L jerrycans or clay pots") should be reworded. That wording is for Amish to decide.
6. Drum brakes with a parking latch; ask users about a dead-man brake.
7. First co-design partner and region.

### Safety concerns

- Runaway on descents: about 55 to 90 N net downhill pull on a 10 % slope when loaded. Needs a service brake on a grip, a parking latch and possibly a dead-man brake.
- Tipping when a wheel drops into a rut on a cross-slope, and shifting loads. Containers must be strapped, and people must not ride.
- Pinch and entanglement at spokes, caster forks and telescopic posts, especially for skirts and children's hands.
- Lithium pack (assist only): BMS, fuse, sand and water protection, and safe charging location. The motor must run only while the user pushes and must cut out when the brake is pulled.
- A single rear hub motor with free casters will yaw the carrier. Lock the casters while assisting, or use two motors.

### Problems found this session

- A shorter frame with limited-swivel casters was modelled first. It could not turn tighter than about 6 m, so the layout was changed to full-swivel casters ahead of the cradle, which lengthened the carrier to 2.2 m.

### Recommended next step

Review this note and the media, and decide the proposed items above. Before `/advance-trl3`, start co-design with a local partner so that the load, container, path width and push-force targets come from users. If approved, `/advance-trl3` should verify the sand rolling resistance, brake sizing, frame stiffness and hub motor torque at walking speed by calculation, and produce the parametric model and drawing sheet.

## Session 2026-09-25: TRL 3

Amish's instruction for this session (2026-09-25): "proceed with all of your recommendations across all batches. Make sure we don't proceed to TRL 4 on any of them." He also approved the SwapCell interface v0.3 additions (wake for hosts without CAN, charge-while-discharging mode, latch vibration rating for vehicles), pricing shared SwapCell packs once, and picking co-design partners per area later. **TRL 4 is on hold by his instruction.**

### What was done

- `docs/decisions/0001-trl2-review-decisions.md` (WWK-DDR-001 v0.1): the six decided TRL 2 items, the cross-cutting approvals as they apply here, and seven open items.
- `docs/04-calcs/01-sizing.md` (WWK-CAL-001 v0.1) with `docs/04-calcs/sizing.py` and `docs/04-calcs/results.csv`: geometry, mass roll-up, push force on firm ground, slopes and sand (sinkage model), assist kit and SwapCell energy, brakes and parking with traction, frame and axle stresses, torsion, turning, stability, cost, and a table of every requirement. The script reads the model parameters and the BOM.
- `cad/src/model.py`: parametric build123d model of the first prototype and the optional assist kit, exporting `cad/step/waterwalker-first-prototype.step`, `-frame.step`, `-assist-kit.step`, `-assembly.step` and `cad/stl/waterwalker-frame.stl`, `-cradle.stl`, `-assembly.stl`.
- `cad/src/sheets.py` and `cad/drawings/WWK-DWG-001.svg`, `.pdf`, `.png`: general arrangement, Rev P1, marked "CONCEPT, NOT FOR FABRICATION" and "PRELIMINARY, NOT FOR FABRICATION". The concept blueprint keeps WWK-DWG-010.
- `bom/bom.csv` (14 lines, every line priced, supplier types) and `bom/bom-notes.md`.
- `cad/src/concept_media.py` now builds from the model; `media/` refreshed (hero, blueprint, exploded with the optional assist kit, flow, `model.glb`, `viewer.html`). Hero, blueprint and viewer show the first prototype without assist. Every image was checked; the temporary `media/_views*` folders were deleted.
- WWK-PRB-001, WWK-PRC-001 and WWK-REQ-001 moved to v0.3 with the decisions, checked numbers and new requirement R13. `project.yaml` is at `trl: 3`, `trl_target: 3` with the evidence listed; the pitch and README are updated.

### Requirements (WWK-CAL-001)

Two met, six at risk, four **not met**, one not verifiable at TRL 3.

| ID | Status | Value against target |
| --- | --- | --- |
| R2 | **Not met** | Firm path 24.6 to 61.4 N against 60 N |
| R3 | **Not met** | Loose sand 242 to 368 N against 150 N; no assist on the first prototype. One motor leaves 135 to 267 N; two motors give 15 to 148 N |
| R4 | **Not met** | 10 % climb 146.7 to 183.4 N against 180 N; descent met on paper (73 N at the lever) |
| R9 | **Not met** | Empty 40.8 kg against 35 kg (47.3 kg against 42 kg with assist) |
| R1 | At risk | Four jerrycans fit with 44 mm spare; two 380 mm clay pots with only 8 mm |
| R6 | At risk | 898 mm wide against 900 mm |
| R7 | At risk | Walking width 610 mm against 600 mm; no step-over |
| R10 | At risk | 189 N at the lever to set the parking latch on 20 %; tire friction 0.41 needed facing downhill |
| R11 | At risk | First prototype $430 against $450 |
| R12 | At risk | 100 mm drum hubs may be scarce in rural markets |
| R5 | Met | Turning circle 3.66 m against 4.0 m |
| R8 | Met | Lift 364 mm against 450 mm |
| R13 | Not verifiable at TRL 3 | Mounting points modelled; latch class V1 retention needs a test |

Key numbers: loaded mass 125.2 kg; centre of mass 364 mm high; side tip angle 47 degrees; frame stress 112 MPa at 2.5 g (factor 2.09); assist 83 Wh/km per motor on sand, 5.4 km per SwapCell pack.

Corrections to TRL 2: empty mass 31 to 40.8 kg (tires, tubes, liners, a second pair of forks and a heavier frame were missing), parts cost $300 to $430 (tires and forks were missing), width 860 to 898 mm, walking width 660 to 610 mm, turning circle 3.8 to 3.66 m, and the assist pack is SwapCell's 46.8 V, not 36 V. Two layout faults were found and fixed in the model as proposals: the cantilevered rear stub axles (about 472 MPa in an M10 axle at 2.5 g) and front risers inside the caster sweep.

### Decisions recorded

Decided by Amish, 2026-09-25: go with recommendation (WWK-DDR-001): 26 x 2.1 to 2.4 in wheels all round; no assist in the first prototype, with mounting points, keeping `budget_usd: 450` and redefining it in R11 as the unassisted first prototype with mounting points; full-swivel lockable casters; user between the rear wheels; four jerrycans or two clay pots (R1 redefined; pitch and README reworded to "four 20 L jerrycans or two clay pots"); rear drum brakes with a parking latch. Cross-cutting: assist mounting points built to SwapCell interface v0.3 items W and V (item C not used), new R13; SwapCell pack priced once in the SwapCell BOM and excluded here.

### Still awaiting Amish

Status update (2026-09-25, WWK-DDR-002): items 3 to 7 are Decided by Amish, 2026-09-25: go with recommendation. Items 1, 2 and 8 have no recommendation and remain Proposed, awaiting Amish.

1. First co-design partner and region (no recommendation; per area later).
2. Dead-man brake (no recommendation until users are asked).
3. Rear wheels in fixed rigid forks with 100 mm drum hubs and a 770 mm track. Recommended; already in the model. Decided by Amish, 2026-09-25: go with recommendation.
4. Front risers moved to x = 1,150 mm, wheelbase 1,530 mm, cradle 780 mm. Recommended; already in the model. Decided by Amish, 2026-09-25: go with recommendation.
5. Main tube 40 x 30 x 1.5 mm. Recommended; already in the model. Decided by Amish, 2026-09-25: go with recommendation (section kept; wall 1.2 mm under item 6).
6. Mass: apply the thinner cradle and 1.2 mm main-tube wall (35.6 kg with all four options, still over 35 kg), and revisit R9 with users. Recommended. Decided by Amish, 2026-09-25: go with recommendation.
7. Parking: add a positive lock pin. Recommended. Decided by Amish, 2026-09-25: go with recommendation.
8. Budget for the later assist prototype (kit $260, or about $450 with two motors, plus a shared pack). No recommendation. Proposed, awaiting Amish.

### Safety concerns

- Runaway and parking on slopes: 61 to 98 N downhill pull on 10 %; the parking latch needs about 189 N at the lever, and on loose ground the rear tires may slide (friction 0.41 needed). A lock pin and chocks help with the first, not the second.
- Weld fatigue at the cradle hangers and caster arm roots is at risk (63 MPa stress range against about 71 MPa for a typical fillet weld detail). Only a test can show it.
- Caster sweep (about 400 mm radius), spokes and forks are pinch and entanglement points for feet, skirts and children's hands.
- The empty carrier weighs about 41 kg, a two-person lift over steps and ditches.
- Later assist: lithium pack in a class V1 receiver, sealed from sand and water but open to air on two faces; motor heat at walking speed (about 107 W per motor on sand); one-motor yaw needs locked casters.

### Existing TRL 4 material

None found. No test articles, test plans, build procedures or purchasing lists exist in this repo, and none were created. `build-log/` holds only its README.

### Citations

The earlier review note listed no unchecked citations. WWK-CAL-001 relies on stated assumptions and standard relations (rigid-wheel sinkage geometry, Bekker's pressure-sinkage scaling, Bredt torsion) and on the SwapCell interface v0.3 values in the SwapCell repo; no new external sources were cited, so no web check was needed.

### Recommended next step

Amish reviews WWK-DDR-001 open items 3 to 8, above all the mass and parking proposals, and decides whether R2, R4 and R9 should be relaxed or the design lightened. Co-design with a local partner (item 1) should then confirm push-force limits, sand sinkage on real routes, clay pot sizes and the brake arrangement before any build. **TRL 4 is on hold by Amish's instruction.** For the record only, TRL 4 would need: the open decisions settled, a first-prototype build budget confirmed, sourcing of 100 mm drum hubs checked, a built frame and carrier, lab test reports (TST, `environment: lab`) for push force, parking on 20 %, frame strength and fatigue, and turning, and build-log entries.

## Session 2026-09-25: recommendations accepted

Amish wrote on 2026-09-25: "i accept all your recommendations, go with them across all repos." Every item with a recommendation is now **Decided by Amish, 2026-09-25: go with recommendation**; items without one stay open. Recorded in `docs/decisions/0002-recommendations-accepted.md` (WWK-DDR-002 v0.1).

### Decisions applied and what changed

| Item | Decision | Change in the repo |
| --- | --- | --- |
| Rear wheels in fixed forks (DDR-001 item 9) | Decided | Already modelled; status only |
| Risers at x = 1,150 mm, wheelbase 1,530 mm (item 10) | Decided | Already modelled; status only |
| Main tube 40 x 30 mm (item 11) | Decided | Section kept; wall set by item 12 |
| Mass (item 12) | Decided: 1.2 mm main wall, thinner cradle, keep puncture protection, revisit R9 with users | Main wall 1.5 to 1.2 mm; cradle floor 9 to 6 mm, walls 6 to 4 mm, pad 4 to 2 mm. Empty mass 40.8 to 37.4 kg; loaded 125.2 to 121.8 kg. Revisiting R9 with users waits for co-design |
| Parking (item 13) | Decided: positive lock pin, latch kept for short stops | New BOM item 15 ($5, 0.10 kg), modelled on the left rear fork, through the left skirt guard and spokes; R10 restated |

Numbers before and after (WWK-CAL-001 v0.1 to v0.2): firm push 61.4 to 59.7 N; 10 % climb 183.4 to 178.3 N; loose sand 242 to 368 N to 236 to 358 N; caster arm stress 112 to 133 MPa (factor 2.09 to 1.77); weld stress range at the rear hanger 63 to 75 MPa; clay pot spare length 8 to 12 mm; parts $430 to $426. Budget: `budget_usd` unchanged at 450; no recommendation changed it.

Files changed: `cad/src/model.py` and all STEP and STL exports; `cad/src/sheets.py` and WWK-DWG-001 (Rev P1 to P2); `cad/src/concept_media.py` and `media/` (hero, blueprint, exploded with callout 15, flow, `model.glb`, `viewer.html`; images checked, `media/_views*` deleted); `bom/bom.csv` and `bom/bom-notes.md`; `docs/04-calcs/sizing.py`, `results.csv` and WWK-CAL-001 v0.2; WWK-PRC-001 v0.4; WWK-REQ-001 v0.4; WWK-PRB-001 v0.4; WWK-DDR-001 v0.2; `project.yaml` (evidence list); `README.md` (concept numbers and the four write-up sections, with a new "What sparked the idea": Aina Wifalk's 1978 rollator). All PDFs regenerated with the designmolecule.com footer.

### Requirement status (WWK-CAL-001 v0.2)

3 met, 7 at risk, 2 **not met**, 1 not verifiable at TRL 3 (was 2, 6, 4 and 1).

| ID | Status | Value against target |
| --- | --- | --- |
| R3 | **Not met** | Loose sand 236 to 358 N against 150 N; no assist on the first prototype |
| R9 | **Not met** | Empty 37.4 kg against 35 kg (43.9 kg against 42 kg with assist) |
| R1 | At risk | Two 380 mm clay pots fit with 12 mm spare |
| R2 | At risk | Firm path 59.7 N against 60 N |
| R4 | At risk | 10 % climb 178.3 N against 180 N |
| R6 | At risk | 898 mm against 900 mm |
| R7 | At risk | Walking width 610 mm against 600 mm |
| R10 | At risk | Lock pin for parking; tire friction 0.41 needed on 20 % |
| R12 | At risk | 100 mm drum hubs may be scarce in rural markets |
| R5 | Met | 3.66 m against 4.0 m |
| R8 | Met | 364 mm against 450 mm |
| R11 | Met | $426 against $450 |
| R13 | Not verifiable at TRL 3 | Mounting points modelled; latch class V1 retention needs a test |

### Still awaiting Amish

1. First co-design partner and region (no recommendation; per area later).
2. Dead-man brake (no recommendation until users are asked).
3. Budget for the later assist prototype (no recommendation).
4. New finding: with the 1.2 mm wall the weld stress range at the cradle hangers is 75 MPa, above the 71 MPa of a typical fillet-welded detail at 2 million cycles. Options: gussets at the hanger and caster arm joints (recommended, small mass), a local 1.5 mm wall at those joints, or accept the risk until a fatigue test. Proposed, awaiting Amish; not applied.

### Cross-repo actions

None. No accepted recommendation for WaterWalker needs a change in another repo; the SwapCell interface v0.3 items were already handled in the previous session.

### Safety concerns

- Weld fatigue at the cradle hangers is now past the reference value (item 4 above).
- The lock pin must be pulled before moving off, and it loads the spokes sideways (about 410 N when parked on 20 %); the pull ring sits at the inner face of the left side rail in the walking space.
- Runaway, traction on loose ground when parked, caster sweep pinch points and the lithium pack of the later assist kit are unchanged from the previous session.

### TRL 4

**TRL 4 remains on hold by Amish's instruction.** `trl: 3` and `trl_target: 3` are unchanged. Revisiting R9 with users, the lock pin and spoke test, and any weld fatigue test are decided in direction but on hold. No build, test, purchasing or firmware work was done.

## Session 2026-09-26: sources strengthened

Amish asked to fix the weaker sources in the README (2026-09-26). Every link below was fetched and checked against the claim it supports. No controlled document changed; `docs/01-problem.md` did not cite the replaced sources.

| Where | Old source | New source |
| --- | --- | --- |
| Burning platform | WHO drinking-water fact sheet (kept) | Same; the 2.2 billion figure is now dated 2022, as the fact sheet states |
| Country row, Niger (was "Niger and the Sahel") | None | [UNICEF Niger, WASH](https://www.unicef.org/niger/water-sanitation-and-hygiene): 56 % have access to a drinking water source. The uncited claim about sandy routes was removed |
| Country row, India (was "Rajasthan and other dry states") | None | [UNICEF India, clean drinking water](https://www.unicef.org/india/what-we-do/clean-drinking-water): 54 % of rural women spend about 35 min a day fetching water; under 49 % of rural people use safely managed water. The uncited claims about desert villages and bicycle repair were removed |
| Country row, Peru (was "Peru and Bolivia") | None | Peer-reviewed study of peri-urban Lima shanty towns ([ScienceDirect, 2025](https://www.sciencedirect.com/science/article/pii/S2667010025003051)): about 350 tanker trucks a day serve some 250,000 homes; a hillside household gets about 1,100 L a month. Bolivia dropped (no verified source) |
| Country row, Japan (Noto) | Wikipedia, 2024 Noto earthquake | [The Japan Times, 23 February 2024](https://www.japantimes.co.jp/news/2024/02/23/japan/society/noto-quake-sparks-water-debate/): up to 135,000 households without running water; nearly 24,000 still without it. The Shika six-litre ration could not be verified and was removed |
| What sparked the idea (Aina Wifalk's rollator) | Wikipedia, Aina Wifalk | [Swedish Institute, sharingsweden.se](https://sharingsweden.se/materials/the-invention-of-the-walker) (1978 prototype, Västerås, polio, never patented) and [Svenskt UppfinnareMuseum](https://svensktuppfinnaremuseum.se/aina-wifalk/) (never patented so it would reach as many people as possible). "Presented in 1978" became "designed the prototype in 1978", as the sources state |

Inspiration unchanged (same event, stronger sources). No budget change.

## Session 2026-09-26: product appearance model and photoreal renders

Amish chose this repo for the first batch of product renders on 2026-09-26. This session adds `cad/src/product_model.py`, a finished-product appearance model for photoreal renders, and points the README hero at `media/render-hero.png` with a link to `media/render-exploded.png`. The render files are produced later by the orchestrator. `cad/src/model.py`, the BOM, the drawings and the controlled documents are unchanged.

### What product_model.py adds

- `product_parts()` in the portfolio format (name, shape, colour, material, BOM line, group, explode offset), with `TITLE` and three `RENDER_VIEWS`: hero (front right, with the person), exploded (front right, with the optional assist kit) and detail (rear right, without the person, showing the walk-in rear).
- Frame from `frame_members()` with rounded tube corners, head tubes with headset cups and top caps, dropout tabs, the galvanized receiver plate, torque-arm tab and sensor boss, black tube end caps, red rear and white front reflectors, a rated load and slope plate and a wordmark on the right side rail.
- Four wheels with treaded tires, alloy rims with a rim bed, 36 laced spokes, hub flanges, axles, axle nuts and valves; round-bladed rigid rear forks and swivel caster forks with red drop-pin knobs; finned drum brake plates with reaction arms.
- Hip bar with a stitched fabric-covered foam pad, telescopic posts with height holes, clamp collars and height pins, rubber hand grips with ribs and end plugs, the brake lever with its parking latch, and brake cables to both rear drums.
- Plywood cradle with a rubber pad, removable divider, zinc corner brackets, two webbing straps with cam buckles, and four jerrycans with handles, ribbed caps and side ribs.
- HDPE skirt guards with rounded corners and bolts; the parking lock pin with its tab, a red pull ring and a lanyard.
- Optional assist kit, shown only in the exploded view: hub motor with flanges and cable, SwapCell pack with handle, accent band and lit charge lights, receiver with guides and preload lever, push sensor with a lit status light.
- Context: the shared clay mannequin (1.75 m, "push" pose with arm angles overridden) walking inside the frame with both hands on the grips and the feet on the ground.

### Where the appearance model differs from model.py

Every main dimension and interface is taken from `PARAMS`, `derived()` and `frame_members()`. The differences below are appearance choices that model.py does not define; none is adopted into the design.

1. **Rubber grips at the front of the grip tubes.** The grips cover x = -110 to 40 mm, next to the hip bar posts, so the hands can sit beside the pad while the hips push on it. model.py shows a plain tube from x = -230 to 60 mm. Proposed, awaiting Amish. Recommendation: keep the grips at the front end and confirm the hand position in co-design.
2. **Grip spacing against the user's shoulders.** The grips follow the side rails, 640 mm apart, about twice shoulder width. With hands on them at 950 mm the mannequin's elbows bend back and its pelvis stands about 140 mm behind the pad, so the hips reach the pad only when leaning in. Proposed, awaiting Amish. Options: keep the grips on the rails (no change), or add inboard grips on the hip bar. Recommendation: no change now; ask users at the first co-design session.
3. **Brake cable routing.** model.py has no cables. The left rear cable is drawn along the underside of the hip bar and down the left post, so no cable crosses the open walk-in rear. Proposed, awaiting Amish. Recommendation: adopt this routing.
4. **Hand holds in the cradle side walls** (two 90 x 26 mm slots per side) and the removable divider drawn between the two rows of jerrycans. The BOM lists dividers but not their position; model.py has neither. Proposed, awaiting Amish. Recommendation: keep both; the hand holds make the empty cradle easier to lift out.
5. **Marking positions.** The rated load and slope plate is drawn on the outer face of the right side rail, with red rear reflectors on the hip bar sleeves and white front reflectors on the front risers (BOM item 12). Proposed, awaiting Amish. Recommendation: adopt, and add a second plate on the inside of the left rail where the user can read it.
6. **Representation only.** Rounded tube corners, round fork blades in place of model.py's rectangular blocks, 36 laced spokes in place of six bars, tire tread, and the jerrycan handles and caps inside the same envelopes. The hip bar is drawn graphite and the cradle natural plywood, rather than the concept media colours. No action needed.

### TRL

This is an appearance model only: no tolerances, no fabrication detail. `trl` stays 3 and `trl_target` stays 3. TRL 4 remains on hold by Amish's instruction. No build, test, purchasing or firmware work was done.

## Session 2026-09-27: kit 1.5.0 and image quality

- Kit 1.5.0 synced: STANDARDS v1.5 (sections 12 to 15: product renders, storefront images and image quality, public release, authorship and signing), `.kit/cards.py`, `.kit/image_qc.py`, `.kit/release_gate.py`, issue templates, and the `/render-product` and `/release` commands. `CLAUDE.md` now matches `.kit/CLAUDE.md`.
- Every `media/render-*.png` recaptioned from its original render with the new layout: the title, concept label and repository sit in a band above the render and the view note in a band below it, each line wrapped to the image width, so no text overlaps other text or the render or runs off the image. `media/card.png` and `media/social-preview.png` regenerated with the same rules.
- `python .kit/image_qc.py` and `python .kit/release_gate.py` pass. trl stays 3.

## Session 2026-10-02: design made constructable and prototype build plan (kit 1.7.0)

Amish approved the build plan format on 2026-09-30 and asked for it in every repo, with outstanding decisions kept in a separate design decisions register. He also wrote: "If you are realising that the design cannot be built as per concept - fix the design assumptions to match and be physically feasible as you draw the illustrations." On 2026-10-01 he set budgets as value-engineering targets. TRL stays 3; nothing was built or bought.

### What was done

- Kit 1.7.0 installed (`.kit/`, `.claude/commands/`); `CLAUDE.md` now matches `.kit/CLAUDE.md`.
- `cad/src/model.py` rewritten so every component is modelled as it is made or bought (`build_components()`), with 79 build123d constructability checks (`python cad/src/model.py --check`, all pass). STEP and STL regenerated.
- `docs/decisions/0003-design-for-construction.md` (WWK-DDR-003 v0.1, Draft): every change below, made under Amish's 2026-09-30 instruction to make the design physically buildable; open for his review.
- `cad/src/build_plan_media.py`: the overview, eight making sketches (`cad/drawings/WWK-DWG-101` to `108`), ten joint close-ups and eleven assembly step pictures in `docs/05-build-plan/`. Every picture was looked at and the unclear ones redrawn.
- `docs/05-build-plan.md` (WWK-BLD-001 v0.1) and `docs/06-design-decisions.md` (WWK-DEC-001 v0.1).
- `docs/04-calcs/sizing.py` and WWK-CAL-001 v0.3: new load path, rear head tube brackets, cradle bearers, lock pin and mass; R11 against the value-engineering target. WWK-REQ-001 v0.5, WWK-PRC-001 v0.5, `bom/bom.csv` (line 16 added) and `bom/bom-notes.md` updated.
- WWK-DWG-001 Rev P3; concept media regenerated (`media/hero.png`, blueprint, exploded, flow, `model.glb`, `viewer.html`).
- `project.yaml`: `design_state: constructable`, the build plan, register and WWK-DDR-003 in `trl_evidence`. README: links line and a "Building the prototype" section.

### Design changes made for construction (WWK-DDR-003)

| # | Change |
| --- | --- |
| P1 | Side rails end at the hip sleeves instead of running through the rear forks; old dropout tabs removed |
| P2 | Each rear head tube held by two brackets 60 mm apart, not one, so parking on one pinned wheel is carried |
| P3 | Rear head tubes 60 mm behind the rear axle, matching the fork offset; one fork part for all four corners |
| P4 | Cradle carrier added: two bearers under the floor on four hangers from the cross members; cradle bolted to it (ground clearance 125 mm) |
| P5 | Rear cross member moved 17.5 mm back, clear of the rear jerrycans |
| P6 | Caster arms run from the top of each riser, angled 8.6 degrees outward, to the side of the head tube; stubs removed |
| P7 | Headsets at all four forks, a lock collar and plate on each steerer, pins into guides on the frame (BOM line 16) |
| P8 | Hip sleeves as tubes with 364 mm posts (150 mm left in at full height), nine height holes and a pin; 22.2 mm grip tubes; sensor tab replaces the solid boss |
| P9 | Drum brake reaction arm clipped along the outer fork blade |
| P10 | Parking lock pin held by tabs on both fork blades; a 10 mm ball-lock pin ending inside the axle nuts |
| P11 | Skirt guards bolted to rail tabs and clipped to the inner blade; slot for the hub so they go on before the wheel |
| P12 | Fork dropouts 6 mm at the axle so the blades clear the hubs |
| P13 | Torque-arm tab welded to the right rear fork, not the frame |
| P14 | Cradle walls with end walls between the side walls and 14 outside angle brackets |
| P15 | Frame members butt on each other's faces with real cut lengths |
| P16 | Receiver plate laps 15 mm onto the upper cross member |

### Key results (WWK-CAL-001 v0.3)

- Empty mass 37.4 to 39.6 kg (+2.2 kg); loaded 124.0 kg.
- **Not met:** R2 firm path 60.8 N against 60 N (was at risk); R3 loose sand 240 to 365 N against 150 N; R4 10 % climb 181.5 N against 180 N (was at risk); R9 39.6 kg against 35 kg.
- At risk: R1, R6, R7, R10, R12. Met: R5, R8. R13 not verifiable at TRL 3.
- Value-engineering target USD 450; estimated cost of the constructable design USD 462 (USD 12 over the target; USD 36 added for construction).
- Frame: caster arm root 129 MPa (factor 1.82); weld stress range in the rail 61 MPa, now below the 71 MPa reference; rear brackets 95 MPa when parked on one pinned wheel (factor 2.5); bearers factor 2.2; lock pin factor 2.0 held at both ends (1.1 at one end, as in the concept).

### Proposed, awaiting Amish (in WWK-DEC-001)

1. Accept the design-for-construction changes P1 to P16. Recommended.
2. R2 and R4 now not met by 0.8 N and 1.5 N: accept on paper and confirm push limits in co-design (recommended), apply the open tire mass options, or lighten the carrier tube.
3. Ground clearance 125 mm under the carrier: accept (recommended) or raise the cradle 25 mm.
4. Unchanged from earlier sessions: co-design partner, dead-man brake, value-engineering target for the assist prototype, weld fatigue (now recommended to wait for a TRL 4 test), and the appearance-model choices of 2026-09-26.

### Safety concerns

- Tabs are now welded to the steel rear forks (lock pin and torque arm); the welds need a skilled welder and inspection (build plan safety stop S1).
- Runaway and parking on slopes are unchanged: tire friction 0.41 needed on 20 %; the lock pin is held at both ends now, but the spokes still take its load in bending.
- The caster sweep (about 400 mm radius, 22.5 mm clear of the risers), spokes and forks remain pinch points; the skirt guards are now fixed at four points.

### Stale media (made on Amish's Mac, not regenerated here)

`media/render-hero.png`, `media/render-exploded.png`, `media/render-detail.png`, `media/card.png` and `media/social-preview.png`, and the appearance model `cad/src/product_model.py`, still show the concept: one rear bracket with the axle under the head tube, caster arms on stubs, 32 mm grip tubes and no cradle carrier. The design changed visibly, so they are stale and need re-rendering with `/render-product`.

### Recommended next step

Amish reviews WWK-DDR-003 and the three new items in WWK-DEC-001. **TRL 4 remains on hold.** For the record only, TRL 4 would start by buying the forks and drum hubs to confirm the items in WWK-DEC-001 Table 2, then building to WWK-BLD-001 and recording the first checks in a test report.

## Session 2026-10-02: open decisions decided

Amish, 2026-10-02: "APPROVED: The open decisions from the last wave (TremorTrace to ZeerBox) came in after the review and aren't on the page either." This approves the recommendation written for each open decision in the design decisions register (WWK-DEC-001), as he did for the other 555 open decisions ("i approve your recommendations for all 555 open decisions."). trl stays 3; no build or test work was done, and the model, BOM quantities and prices, and pictures are unchanged.

### Decisions recorded

Eight decisions, all moved to Decisions made in WWK-DEC-001, dated 2026-10-02:

1. Design for construction accepted: the changes P1 to P16 of WWK-DDR-003, as made.
2. R2 and R4: accepted as not met on paper by 0.8 N and 1.5 N; the puncture protection chosen on 2026-09-25 is kept, and the push limits are confirmed with users in co-design.
3. Ground clearance: 125 mm under the cradle carrier accepted; a clearance figure is added to the requirements after the first route survey.
4. First co-design partner and region: the Helpful Engineering network is the route to a first partner, a university engineering department or water and sanitation NGO in semi-arid eastern Kenya, where water is carried along sandy routes and dry riverbeds; Kitui County is the first candidate region.
5. Dead-man brake: a hold-to-release (dead-man) brake is fitted on the first prototype: a spring applies both rear drum brakes unless the user holds a bail on the grips, kept alongside the service lever, parking latch and lock pin; users are asked about it in co-design, and it is dropped only if descent trials and users show the latch and pin are reliably used.
6. Value-engineering target for the later assist prototype: about USD 450 for the two-motor assist kit (two rear hub motors with their controller and push sensor), with the shared SwapCell pack counted separately; the USD 260 one-motor kit is used only if sand trials show one motor meets R3.
7. Weld fatigue: the frame joints are accepted without gussets until a fatigue test at TRL 4 (61 MPa stress range in the rail, below the 71 MPa reference), and the rear cross member and caster arm welds are inspected at every service until then.
8. Appearance-model choices: the left brake cable along the hip bar, the hand holds in the cradle side walls and the rated load and slope plates are adopted; grip position and spacing are asked of users at the first co-design session.

### Documents changed

- `docs/06-design-decisions.md` (WWK-DEC-001 v0.2): open decisions moved to Decisions made.
- `docs/decisions/0003-design-for-construction.md` (WWK-DDR-003 v0.2): acceptance recorded in the status line; A1 and A2 decided (record stays Draft).
- `docs/decisions/0001-trl2-review-decisions.md` (WWK-DDR-001 v0.3): items 7 and 8 recorded as decided.
- `docs/decisions/0002-recommendations-accepted.md` (WWK-DDR-002 v0.2): items 7, 8 and 14 recorded as decided.
- `docs/01-problem.md` (WWK-PRB-001 v0.5): partner and region answered.
- `docs/02-concept.md` (WWK-PRC-001 v0.6): brake choice, runaway safety note, assist target and partner.
- `docs/03-requirements.md` (WWK-REQ-001 v0.6): R2 and R4 notes; no status changed.
- `bom/bom-notes.md`: assist prototype target; dead-man brake noted as not yet a BOM line.
- `README.md`: the build plan paragraph says the decisions are all made.

### Follow-up actions to carry approved decisions into the design

1. Decision 5 (model): Model the hold-to-release brake: a bail on the grips, a return spring and the cable route to both rear drums alongside the service lever, with clearance checks.
2. Decision 5 (BOM): Add the hold-to-release brake parts (bail lever, spring, cable and splitter) to the BOM with a price basis.
3. Decision 5 (calculations): Add the brake's mass to the roll-up and re-run the push forces (R2, R4, R9) and the descent and parking checks in WWK-CAL-001.
4. Decision 5 (pictures): Add the dead-man brake to the general arrangement, the build plan's brake step, wiring and cable picture, and a safety stop that tests it before the first loaded descent.
5. Decision 6 (model): Add a torque-arm tab to the left rear fork as well, so the two-motor assist kit bolts on, and update the assist mounting description.
6. Decision 6 (calculations): State the assist prototype's value-engineering target (about USD 450, two motors, pack excluded) in WWK-CAL-001 and the concept cost row.
7. Decision 7 (docs): Add a weld inspection of the rear cross member and caster arm joints to the build plan's checks and service notes, pending the TRL 4 fatigue test.
8. Decision 8 (model): Add the hand holds in the cradle side walls, the left brake cable along the hip bar and the rated load and slope plates to the model and drawing.
9. Decision 4 (docs): Approach a university engineering department or water and sanitation NGO in Kitui County through the Helpful Engineering network.

### Points found in the review

- A dead-man brake (item 5) adds a little mass, so R2 and R4 move slightly further from their limits; the push-force calculation needs re-running when it is modelled.
- Item 6 is labeled a budget in WWK-DDR-002 item 14; under the 2026-10-01 rule it is a value-engineering target, not a limit.
- The concept's assist description (one hub motor in a rear wheel, step 6) and BOM notes (USD 260 kit) describe one motor, while the calculation and R3 note say two are needed on the loosest sand.

## Session 2026-10-02: approved follow-ups carried out

Amish, 2026-10-02: "497 follow-up actions that need CAD, drawing, picture, BOM or calculation work ... APPROVED CHANGES, COMPLETE THESE", and for the renders: "Photoreal renders are out of date in most repos ... COMPLETE THESE". trl stays 3; nothing was built, bought or tested.

### Follow-ups

1. Decision 5 (model): **done.** `cad/src/model.py` adds the hold-to-release brake (BOM line 17): a bail lever clamped on the left grip tube, a spring unit (26 mm tube, 132 mm long, with toggle and cable yoke) held by two saddle clips on a 4 mm tab welded to the outer face of the left hip sleeve, a bail cable, the service lever cable along the front of the hip bar to the yoke, and a cable from the yoke to each rear drum, passing in front of and outside each rear head tube and down the front of the outer fork blade, inside the width over the axle nuts. 18 new constructability checks (bail on the grip tube and clear of the grip, unit on its tab and clear of the brackets, height pin, wheel, fork and collar, cables clear of frame, hip bar, wheels, forks, tabs, lock pin, guards, headsets, sensor and motors, cables meeting the unit): 104 of 104 pass. STEP and STL regenerated.
2. Decision 5 (BOM): **done.** New line 17, USD 30, with a price basis per part; line 7 USD 20 to USD 16 (splitter replaced by the yoke); see `bom/bom-notes.md`.
3. Decision 5 (calculations): **done.** WWK-CAL-001 v0.4: brake 0.60 kg in the roll-up; R2 61.2 N, R4 182.6 N, R9 40.3 kg; spring 390 N (hold on 10 % with the assisted mass, margin 1.25), holds up to 12 % alone, stops in about 2.6 m if let go at 1.0 m/s on 10 %; squeeze 98 N, hold 24 N (toggle factor is an estimate); parking on 20 % still needs the latch or lock pin (192 N latch, friction 0.41).
4. Decision 5 (pictures): **done.** WWK-DWG-001 Rev P4; overview; new joint 11 (spring unit); step 8 (bail and grips) and new step 9 (spring unit and cables); old steps 9 to 11 are now 10 to 12; safety stop S4 tests the brake before the first loaded descent; WWK-BLD-001 v0.2 section 3.9 describes it.
5. Decision 6 (model): **done.** Torque-arm tab on the left rear fork as well (checks: on the blade, clear of wheel, brake arm, lock pin tabs and pin); two hub motors in the assist kit; mounting description updated in WWK-PRC-001 v0.7 and WWK-DWG-105.
6. Decision 6 (calculations): **done.** WWK-CAL-001 v0.4 section 5 and the precis: "Value-engineering target: USD 450. Estimated cost of the two-motor kit: USD 450 (on the target)", pack excluded; BOM line 9 quantity 2.
7. Decision 7 (docs): **done.** Weld inspection of the rear cross member and caster arm joints added to the build plan's first checks and as safety stop S6 (every service until the TRL 4 fatigue test).
8. Decision 8 (model): **done.** Hand holds (two 90 x 26 mm slots per side wall), the left brake cable along the hip bar (the service cable now crosses along the front of the pad to the left-side unit) and two rated load and slope plates (right rail outside, left rail inside) are in the model, the GA and WWK-DWG-108.
9. Decision 4 (outreach): **not done:** outreach by Amish through the Helpful Engineering network.

### Requirement status

No status changed. R2 not met by 1.2 N (was 0.8 N), R4 by 2.6 N (was 1.5 N), R9 40.3 kg (49.6 kg with the two-motor kit), R10 at risk, R11 over the target by USD 42. With the second motor's mass counted, the two-motor kit leaves 154 N on the loosest sand, 4 N over R3 (144 N in v0.3); a motor of about 41 N·m closes it.

### Cost and mass

Value-engineering target: USD 450. Estimated cost of the constructable design: USD 492 (USD 42 over the target). Empty mass 40.3 kg; loaded 124.7 kg.

### Documents changed and new versions

`cad/src/model.py`; `cad/step/*`, `cad/stl/*`; `bom/bom.csv`, `bom/bom-notes.md`; `docs/04-calcs/sizing.py`, `results.csv`, WWK-CAL-001 v0.4; WWK-REQ-001 v0.7; WWK-PRC-001 v0.7; WWK-DEC-001 v0.3; WWK-BLD-001 v0.2; README; `cad/src/sheets.py` and WWK-DWG-001 Rev P4; `cad/src/build_plan_media.py` with WWK-DWG-101, 102, 105 and 108, overview, joints 1, 5, 7 and 11, steps 2, 4, 5 and 7 to 12; `cad/src/concept_media.py` (blueprint Rev P3, hero, exploded, flow, `model.glb`, `viewer.html`); `cad/src/product_model.py`. The drawing scripts share `patch_svg_export()` in `model.py`, which draws the few degenerate arcs the cables project to as short lines.

### Appearance model and render scenes

`cad/src/product_model.py` now builds the frame, brackets, carrier, forks, headsets, collars, tabs, guards, hip bar, brakes, cradle, plates, lock pin and assist kit directly from `model.build_components()`, so it matches the constructable design; wheels, jerrycans, straps, pad, grips, reflectors and end caps are drawn on model.py's dimensions. RENDER_VIEWS kept (hero, exploded, detail). Scenes exported to `/home/claude/renders/waterwalker` (one .npz and .json per view and `waterwalker__jobs.json`). Photoreal renders, `card.png` and `social-preview.png` are to be made on Amish's Mac. Proposed, awaiting Amish: the rubber grips and the mannequin's hands now sit on model.py's grips (230 to 100 mm behind the axle), so the figure stands about 165 mm further back than in the 2026-09-26 renders and its hips do not touch the pad; recommendation: keep, since grip position is asked of users at the first co-design session.

### Cross-repo actions

- SwapCell: the WaterWalker assist kit now draws up to 7.8 A from the pack through two controllers; no change to interface v0.3 is needed (for information only).

### Safety

The hold-to-release brake does not park on 20 %; the latch and lock pin remain the parking brakes. The hold force depends on an estimated toggle factor and must be measured at TRL 4 before users rely on it.

### Recommended next step

Amish reviews the renders made from the new scenes. TRL 4 remains on hold.

## 2026-10-02: photoreal renders redone on the constructable design

Rendered with Blender Cycles on Amish's Mac from the updated appearance model; captioned with `.kit/photo_caption.py`; `media/card.png` and `media/social-preview.png` regenerated with `.kit/cards.py`. Views: hero, exploded, detail. image_qc passes. Appearance deviations are those logged above as proposed, awaiting Amish.

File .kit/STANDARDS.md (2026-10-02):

---
doc_id: OHP-STD-001
title: Documentation and drawing standard
project: Open Hardware Portfolio
doc_type: Standard
version: "1.7"
status: Released
date: 2026-09-30
author: Amish Chadha
license: CC-BY-SA-4.0
revisions:
  - version: "1.0"
    date: 2026-09-24
    author: Amish Chadha
    change: First release of the standard
  - version: "1.1"
    date: 2026-09-24
    author: Amish Chadha
    change: Adopt Technology Readiness Levels (section 9) for project maturity
  - version: "1.2"
    date: 2026-09-24
    author: Amish Chadha
    change: Portfolio phase cap (section 10), concept media standard (section 11), CLAUDE.md guardrails
  - version: "1.3"
    date: 2026-09-24
    author: Amish Chadha
    change: Scale figure, interactive 3D viewer and flow diagrams added to concept media; session slash commands
  - version: "1.4"
    date: 2026-09-26
    author: Amish Chadha
    change: Every sheet and render names the project and its GitHub repository; overall dimensions, ISO centre lines and 300 dpi PNG on sheets; titles name the device and view labels state the viewing direction; optional photoreal renders with Blender
  - version: "1.5"
    date: 2026-09-27
    author: Amish Chadha
    change: Product renders (section 12), storefront images and image quality check (section 13), public release and release gate (section 14), authorship, citation and commit signing (section 15)
  - version: "1.6"
    date: 2026-09-29
    author: Amish Chadha
    change: Licensing metadata with REUSE (section 16), Zenodo DOI and Software Heritage archiving (section 17), release gate checks REUSE and a single CITATION.cff license, archive.py
  - version: "1.7"
    date: 2026-09-30
    author: Amish Chadha
    change: Concept and constructable design states; design decisions register (DEC) kept apart from the build plan; prototype build plan (BLD, section 18) with pictures by component is required TRL 3 evidence; every repo targets TRL 3 during the populate phase; build_views.py; /to-trl3 and /build-plan commands
---

# Documentation and drawing standard

Every project in the portfolio uses this standard, so that each precis, write-up and sketch looks the same and carries its own version history. The standard ships as a kit in each repo's `.kit/` folder. The kit version is in `.kit/KIT_VERSION`.

## 1. Document types and IDs

Every controlled document has a unique ID in the form `PRJ-TYP-NNN`.

- `PRJ` is the three-letter project code listed in section 7.
- `TYP` is the document type code from the table below.
- `NNN` is a sequence number within that project and type, starting at 001.

| Code | Type | Typical file |
| --- | --- | --- |
| PRC | Design precis | `docs/02-concept.md` |
| PRB | Problem statement | `docs/01-problem.md` |
| REQ | Requirements | `docs/03-requirements.md` |
| CAL | Calculation or sizing note | `docs/04-calcs/*.md` |
| DDR | Design decision record | `docs/decisions/*.md` |
| BOM | Bill of materials | `bom/bom.csv` |
| DWG | Drawing or sketch sheet | `cad/drawings/*.svg` |
| BLD | Prototype build plan (section 18) | `docs/05-build-plan.md` |
| DEC | Design decisions register (section 18) | `docs/06-design-decisions.md` |
| TST | Test plan or test report (front matter adds `environment: lab` or `relevant`) | `docs/05-tests/*.md` |

Example: `TBK-PRC-001` is the ThermaBrick design precis.

## 2. Revision scheme

| Artifact | While in draft | When released | Change after release |
| --- | --- | --- | --- |
| Documents | 0.1, 0.2, 0.3 ... | 1.0 | 1.1 for minor edits, 2.0 for a design change |
| Drawings | Rev P1, P2 ... (preliminary) | Rev A | Rev B, C ... |

- Every change to a controlled document adds a row to its revision history before the commit.
- The `version` field in front matter always equals the newest row in `revisions`. The renderer rejects a document where they differ.
- Status is one of `Draft`, `In review`, `Released` or `Superseded`. Draft and In review documents print with a status band on every page.
- Every release is tagged in Git as `<doc_id>/v<version>`, for example `TBK-PRC-001/v1.0`. Drawings are tagged `TBK-DWG-001/revA`.
- Git history is the full audit trail. The in-document revision table is the human-readable summary.

## 3. Document front matter

Every Markdown document under version control starts with this block:

```yaml
---
doc_id: TBK-PRC-001
title: ThermaBrick design precis
project: ThermaBrick
doc_type: Precis
version: "0.1"
status: Draft
date: 2026-09-24
author: Amish Chadha
license: CERN-OHL-S-2.0
revisions:
  - version: "0.1"
    date: 2026-09-24
    author: Amish Chadha
    change: Initial draft
---
```

Quote version numbers so YAML keeps `1.0` as text instead of turning it into a number. List revisions newest last.

## 4. Writing style

- Chicago Manual of Style.
- No em dashes. Restructure the sentence instead.
- Lead each section with its conclusion, then support it.
- SI units throughout, in the form `12 kW`, `450 °C`, `3.2 m`. Imperial values may follow in parentheses.
- Number every figure and table ("Figure 2", "Table 1") and give each a caption.
- State every assumption in the calculation that depends on it.
- Put safety notes in a blockquote starting with **Safety:**.

## 5. Visual identity

| Element | Specification |
| --- | --- |
| Typeface | IBM Plex Sans for text, IBM Plex Mono for code and values (SIL Open Font License, bundled in `.kit/fonts`) |
| Ink | `#111827` |
| Secondary text | `#4B5563` |
| Rules and grid | `#D1D5DB` |
| Accent (one only) | `#0F766E` teal |
| Document page | US Letter, 20 mm margins |
| Drawing sheet | ANSI B landscape (431.8 x 279.4 mm) |
| Footer | Document ID, version, status, license and designmolecule.com on every page |

## 6. Drawing and sketch conventions

- Units are millimeters unless the title block says otherwise.
- Third-angle projection, marked with the symbol in the title block.
- Line weights: visible outlines 0.5 mm, hidden lines 0.25 mm dashed, center lines 0.18 mm chain.
- The title block contains the project, title, drawing number, revision, scale, units, projection, sheet, author, date, material or notes, and license.
- Every sheet and every render names the project and its GitHub repository (from `repo:` in `project.yaml`), at the top of the sheet and in the title block, so a printed or forwarded sheet is never anonymous.
- The drawing title names the device, not only the drawing type (for example "Handheld near-infrared resin scanner: general arrangement").
- Every view label states its scale and viewing direction (for example "Scale 1:1; side elevation looking along +Y"), and every isometric or render states where it is seen from.
- Orthographic views generated with `add_ortho` carry overall dimensions (length and depth on the top view, height on the front view) and ISO 128 centre lines on cylinders; hidden lines are dashed. Tolerances are not shown before TRL 4.
- Sheets are exported as SVG, PDF and a 300 dpi PNG.
- The revision table in the top right of the sheet lists every revision.
- Concept sketches use the same sheet and title block and carry the label "CONCEPT, NOT FOR FABRICATION".
- Geometry comes from `cad/src/*.py` (build123d). Sheets are generated by `.kit/drawing.py` and never edited by hand.

## 7. Project codes

| Code | Project | Code | Project | Code | Project |
| --- | --- | --- | --- | --- | --- |
| TBK | ThermaBrick | PCF | PicoFlow | HLT | HelioLite |
| CCB | CharCube | DRN | DustRunner | TRT | TremorTrace |
| STC | StepCue | FXH | FlexHand | CPD | ColdPod |
| SCL | SunClave | STR | SteamRoot | GGD | GrainGuard |
| SDL | SeedLine | ZBX | ZeerBox | RMS | RootMesh |
| DWD | DewDrive | SSK | StillStack | PPR | PotPress |
| WWT | WaterWatch | LMF | LumaFlow | FCL | FieldCell |
| CNP | ConePro | CVC | CulvertCrawl | EGD | EmberGuard |
| SNF | SnapFrame | CGM | CargoMule | SCM | StepClimber |
| SWC | SwapCell | PLP | PalletPilot | FTK | FlatTrike |
| WWK | WaterWalker | GRR | GrowRider | SSP | SunSpoke |
| SGN | StepGen | PBX | PowerBox | WML | WasteWise-ml |
| WSC | WasteWise Scan | RFE | ReflowEconomy | | |
| OHP | Portfolio-wide | | | | |

## 8. Build and publish

- `python .kit/render.py` checks every controlled document and renders it to `docs/pdf/<doc_id>_v<version>.pdf`.
- `python .kit/drawing.py` (called from each project's `cad/src/sheets.py`) builds drawing sheets as SVG and PDF in `cad/drawings/`.
- The GitHub Action in `.github/workflows/docs.yml` runs the checks on every push and attaches PDFs to a GitHub Release whenever a release tag is pushed.
- Public releases follow section 14: `python .kit/release_gate.py` must pass, and the release tag is `v0.<TRL>.0` (for example `v0.3.0` at TRL 3).

## 9. Technology Readiness Level (TRL)

Each project states its maturity as a Technology Readiness Level on the NASA and US DOE 1 to 9 scale. The TRL rates this specific design, not the underlying technology. A sand battery is commercial elsewhere, but a new sand battery design starts at TRL 2 until evidence shows otherwise.

| TRL | Definition | Evidence the repo must contain |
| --- | --- | --- |
| 1 | Basic principles observed | Problem statement (PRB) |
| 2 | Technology concept formulated | Draft precis (PRC) and requirements (REQ) |
| 3 | Analytical or experimental proof of concept | Calculation note (CAL), working build123d model with STEP export, drawing sheet (DWG), priced BOM with every unit cost filled in, prototype build plan (BLD) with pictures, `design_state: constructable` |
| 4 | Components validated in the lab | Test report (TST) with `environment: lab`, build log entries |
| 5 | Validated in a relevant environment | Test report (TST) with `environment: relevant` |
| 6 | System prototype demonstrated in a relevant environment | Precis at version 1.0 or later with status Released, a drawing at a lettered revision (Rev A or later), and a system-level TST with `environment: relevant` |
| 7 to 9 | Operational demonstration through proven in service | Beyond portfolio scope; claim only with a named deployment partner and evidence |

Rules:

- `project.yaml` records `trl` (current level), `trl_target` (the level the current effort aims for) and `trl_evidence` (the files that support the claim).
- `python .kit/render.py --check` fails if the evidence for the claimed TRL is missing. CI runs this check on every push.
- Documentation alone cannot go past TRL 3. TRL 4 and above require hardware and a test report.
- TRL and visibility are independent. A repo can be public at TRL 3 as a documented design ready to build.
- A change of TRL is recorded in the build log with the date and the evidence that justified it.

## 10. Portfolio phase and TRL cap

`.kit/PHASE.yaml` sets the current phase. During the **populate** phase every repo is capped at **TRL 3**: `trl` and `trl_target` may not exceed 3, and the check fails if they do. Every repo targets the cap: `trl_target` must equal 3, so a new repo is taken all the way to TRL 3 (scaffold, populate and advance, see `/to-trl3`). Work that belongs to TRL 4 or later (building or testing hardware, test articles, test plans and reports, build-log entries, purchasing lists, PCB layouts) must not be started. The prototype build plan (BLD, section 18) is TRL 3 paper work and is required. Where it already exists it is kept, flagged in the check output, and not extended. Only Amish changes `PHASE.yaml`.

Every repo carries a `CLAUDE.md` with the working rules for AI sessions: the TRL cap, decision rights (nothing is recorded as decided unless Amish decided it), one step per session, and a mandatory `docs/REVIEW.md` before stopping.

## 11. Concept media

Every repo at TRL 2 or above explains its idea visually. Media are generated from a build123d massing model with `.kit/concept.py`, never drawn by hand, so they stay in step with the design.

| File | Required | Purpose |
| --- | --- | --- |
| `media/hero.png` | TRL 2+ | Shaded isometric render with a 1.75 m person for scale; the website card image |
| `media/concept-blueprint.png` and `.pdf` | TRL 2+ | Blueprint concept sheet: orthographic and isometric views, scale, key figures, title block |
| `media/model.glb` and `media/viewer.html` | TRL 2+ | Interactive 3D viewer (glTF plus model-viewer) for the website |
| `media/cutaway.png` | When the inside matters | Section view showing internal parts |
| `media/exploded.png` | Recommended | Exploded view with numbered callouts matching the BOM |
| `media/flow.png` | When energy or material moves | System, energy or material flow diagram with losses |

Session commands in `.claude/commands/` (`/populate`, `/advance-trl3`, `/rein-in`, `/refresh-media`) carry the standard prompts, so every Claude Code session starts from the same instructions.

At TRL 2 a massing model is enough: correct overall proportions and main components. All concept media carry "CONCEPT, NOT FOR FABRICATION". The check warns when required media are missing at TRL 2 and fails at TRL 3.

## 12. Product renders

Every repo at TRL 3 shows the product as it would look, not only as a massing model.

- `cad/src/product_model.py` is the appearance model. It defines `product_parts()` (named parts with a shape and a material), `TITLE` ("Name: what it is") and `RENDER_VIEWS`. It is for renders only: every main dimension comes from `cad/src/model.py`, never typed in again.
- Where the appearance model departs from `model.py` (a chamfer, a label, a fastener drawn for realism), record the deviation in `docs/REVIEW.md` as "Proposed, awaiting Amish".
- Scale comes from context, not from a floating figure: a hand or forearm for handheld objects, and the posed mannequin (`mannequin()` in `.kit/context_parts.py`: stand, walk, push, ride, sit, reach) for anything a person uses at body scale.
- Renders are made with `.kit/export_views.py` (one scene per view) and `.kit/photoreal.py` (Blender Cycles), then captioned with `.kit/photo_caption.py`. Files are `media/render-<view>.png`; `media/render-hero.png` is required.
- Every caption names the project, the repository and the viewing direction, and carries "CONCEPT, NOT FOR FABRICATION".
- Captions never sit on the render. `.kit/photo_caption.py` adds a header band (title, concept label, repository) above the render and a footer band (view note) below it, wraps every line to the image width, and steps the font down to a floor before adding a line.
- The README opens with `media/render-hero.png`.
- Software-only and scene repositories (no single product) may use a scene render as the hero instead of a product model.
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

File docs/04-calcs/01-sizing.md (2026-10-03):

---
doc_id: WWK-CAL-001
title: WaterWalker sizing calculations
project: WaterWalker
doc_type: Calculation note
version: "0.4"
status: Draft
date: '2026-10-02'
author: Amish Chadha
license: CERN-OHL-S-2.0
revisions:
- version: "0.1"
  date: '2026-09-25'
  author: Amish Chadha
  change: First TRL 3 sizing note (geometry, mass, push force on firm ground, slopes and sand, assist, brakes, frame, axles, turning, cost, requirement table)
- version: "0.2"
  date: '2026-09-25'
  author: Amish Chadha
  change: Recommendations accepted by Amish (DDR-002); 1.2 mm main-tube wall, thinner cradle and parking lock pin applied; all results recalculated
- version: "0.3"
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

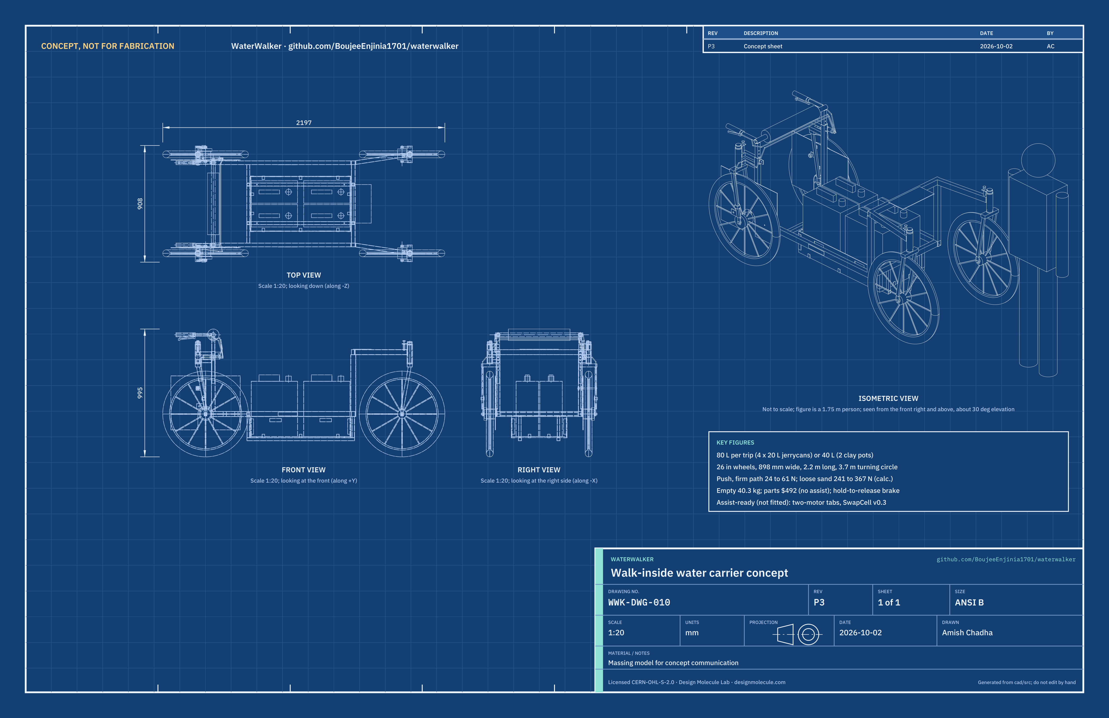
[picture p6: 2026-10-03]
media/concept-blueprint.png

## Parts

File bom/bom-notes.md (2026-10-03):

# BOM notes

Every line in `bom/bom.csv` is priced (TRL 3). Prices are estimates for a one-off purchase in 2026 US dollars, with a supplier or supplier type; they are not quotes. Item numbers match the exploded view (`media/exploded.png`), the components table in WWK-PRC-001 and drawing WWK-DWG-001; items 12 and 14 are not modelled; item 15 is the parking lock pin; item 16 (headset and steering lock sets) was added when the design was made constructable (WWK-DDR-003); item 17 (hold-to-release brake) was added when Amish's decisions of 2026-10-02 were carried into the design; the rating plates in item 12 are modelled. The totals below are printed by `docs/04-calcs/sizing.py` (WWK-CAL-001 v0.4).

| Build | Items | Parts cost |
| --- | --- | --- |
| First prototype, no assist, with mounting points | 1 to 5, 7, 8, 12, 14 to 17 | USD 492 |
| Optional two-motor assist kit (later prototype) | 9 (two), 11, 13 | USD 450 |
| SwapCell pack | 10 | USD 0 here; about USD 414 in the SwapCell BOM |

- **Value-engineering target.** `budget_usd: 450` in `project.yaml` is a hypothetical control target, not a limit (Amish, 2026-10-01). Value-engineering target: USD 450. Estimated cost of the constructable design: USD 492 (USD 42 over the target). Cost drivers and savings worth trying are in the design decisions register (WWK-DEC-001).
- **Changes from the decisions of 2026-10-02.** New item 17, hold-to-release brake, USD 30 (bail lever about USD 8 as a long bicycle or mower-style lever; tube, end caps and toggle about USD 8 from a welder; spring about USD 4 from a spring stockist; cable yoke about USD 5; cables and housing about USD 5); item 7 USD 20 to USD 16 (the splitter is replaced by the yoke in item 17); item 1 USD 61 to USD 62 (second torque-arm tab and the spring unit tab); item 12 USD 22 to USD 25 (two rating plates from a local sign maker); item 9 quantity 1 to 2 (two-motor assist kit). Net USD 30 on the first prototype; USD 190 on the assist kit.
- **Changes from WWK-DDR-003 (2026-10-02, design for construction).** Item 1 USD 55 to USD 61 (cradle carrier, second rear brackets, pin guides, guard tabs); item 3 USD 38 to USD 32 each (headset and swivel lock moved to item 16); item 5 USD 20 to USD 25 (angle brackets and bolts); item 8 USD 6 to USD 7 each (clips and bolts); item 12 USD 20 to USD 22; item 15 USD 5 to USD 6 (second tab, ball-lock pin); new item 16, four headset and steering lock sets at USD 8. Net USD 36.
- **Changes from WWK-DDR-002 (2026-09-25).** Amish accepted the remaining recommendations: the main tube wall drops from 1.5 to 1.2 mm (item 1), the cradle is thinner (item 5), and a parking lock pin is added (item 15).
- **Assist kit.** The two motors, sensor and receiver are outside the first prototype. Meeting R3 on loose sand needs two motors, so Amish set the assist prototype's value-engineering target at about USD 450 for the two-motor kit, pack excluded (2026-10-02, WWK-DEC-001). Value-engineering target: USD 450. Estimated cost of the two-motor kit: USD 450 (on the target). The USD 260 one-motor kit is used only if sand trials show one motor meets R3.
- **Shared packs.** By Amish's 2026-09-25 portfolio rule, the SwapCell pack is priced once in the SwapCell BOM and excluded here.
- The jerrycans (item 6) are the users' own containers and are not purchased.
- All wear parts are standard 26 in bicycle parts (R12), but 100 mm drum hubs are less common in rural markets than rim-brake hubs, so R12 is at risk until checked with a local mechanic.

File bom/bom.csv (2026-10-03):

item | qty | spec | supplier | unit_cost_usd | make_buy | notes
1 Steel tube frame with assist mounting points | 1 | Mild steel RHS 40 x 30 x 1.2 mm (side rails, front risers, angled caster arms, front lower and upper cross members), square 25 x 25 x 1.5 mm (rear cross member, rear head tube brackets at two levels, cradle bearers), 30 x 30 x 1.5 mm hip bar sleeves and 20 x 20 x 1.5 mm cradle hangers, about 9.7 m in total; four head tubes 44 mm OD for EC34 cups; pin guides; skirt guard tabs; mounting points for the assist kit (receiver plate, sensor tab; torque-arm tabs are welded to both rear forks); a 4 mm tab on the left hip sleeve for the hold-to-release spring unit | Local steel stockist and welder | 62.00 | make | Tube about $27 (cut list from cad/src/model.py, WWK-CAL-001 v0.3), head tubes $16, plate, tabs and guides $6, welding consumables $12; cradle carrier and two-level rear brackets added for construction (WWK-DDR-003); spring unit tab and second torque-arm tab added 2026-10-02 (about $1 of flat bar)
2 Rear wheel in fixed fork | 2 | 26 in (ETRTO 559) alloy rim, 36 spokes, 100 mm front-type drum-brake hub (70 mm drum) with reaction arm and clip, rigid 26 in steel fork with 1 1/8 in steerer and 100 mm dropouts, fitted in a headset and locked straight by a pin (item 16) | Bicycle parts dealer | 52.00 | buy | Built wheel with drum hub about $40, rigid fork about $12; headset and lock are item 16; tire, tube and liner are item 14; tabs welded to the forks are items 1 and 15
3 Front wheel on caster fork | 2 | 26 in alloy rim, 36 spokes, 100 mm plain hub, rigid 26 in steel fork with 1 1/8 in steerer, offset about 60 mm (the caster trail), turned to trail behind the steering axis | Bicycle parts dealer | 32.00 | buy | Built wheel about $20, fork $12; headset and swivel lock are item 16; tire, tube and liner are item 14
4 Hip bar and hand grips | 1 | 32 mm x 1.5 mm steel tube bar with foam pad, 25 x 25 x 1.5 mm telescopic posts 364 mm long with nine height holes and two pins (850 to 1050 mm), 22.2 mm x 1.6 mm rear-facing grip tubes, bicycle grips | Local stockist and bicycle parts dealer | 18.00 | make | Estimate
5 Padded cradle | 1 | 6 mm exterior plywood floor 780 x 430 mm, 4 mm plywood walls 160 mm high (end walls between the side walls), 14 zinc angle brackets with M4 bolts, 2 mm rubber pad cut from used inner tubes or tires, two adjustable straps, removable divider; bolted to the frame's cradle bearers with four M6 bolts | Local timber yard and market | 25.00 | make | Holds four 20 L jerrycans or two 20 L clay pots (WWK-DDR-001); thinner cradle (WWK-DDR-002); brackets and bolts added for construction (WWK-DDR-003)
6 20 L jerrycan | 4 | User's own containers, about 360 x 175 x 430 mm | User | 0.00 | buy | Not purchased; shown for scale
7 Brake lever with parking latch and service cable | 1 | Brake lever with parking latch on the right grip; its cable and housing run under the right end of the hip bar and along the front of the pad to the cable yoke in the hold-to-release spring unit (item 17) | Bicycle parts dealer | 16.00 | buy | Lever about $10, cable and housing about $6; the splitter is replaced by the yoke in item 17 (2026-10-02); drums are in the item 2 hubs
8 Skirt guard | 2 | HDPE sheet 540 x 420 x 3 mm with a 120 mm slot for the hub, fitted between the inner fork blade and the spokes; two M6 bolts into tabs on the side rail and two rubber-lined clips with 5 mm spacers on the inner fork blade | Local market or plastics supplier | 7.00 | make | Clips and bolts added for construction (WWK-DDR-003)
9 Optional hub motor kit | 2 | 250 W 48 V geared front-type hub motor (100 mm) laced into a 26 in rim, controller with brake cut-off inputs, torque arm, mechanical disc brake for the motor wheel; one in each rear wheel, bolted to the torque-arm tab on each rear fork | E-bike parts supplier | 190.00 | buy | Optional; later assist prototype outside the first-prototype target (WWK-DDR-001); two motors per Amish's 2026-10-02 decision (value-engineering target about USD 450 for the kit, pack excluded); the motor wheels replace the drum hubs, so the yoke cables go to their disc brakes and the bail also works the brake cut-off
10 Optional SwapCell pack | 1 | SwapCell interface v0.3 pack, 13S2P, 46.8 V nominal, about 450 Wh, 2.85 kg | SwapCell project (SwapCell BOM) | 0.00 | make | Priced once in the SwapCell BOM (about $414) and excluded here by Amish's 2026-09-25 rule
11 Optional push sensor and controller | 1 | 50 kg load cell in the hip bar mount, amplifier, microcontroller, brake cut-off switch | Electronics distributor | 25.00 | buy | Optional; no firmware at TRL 3
12 Hardware and consumables | 1 | Bolts, nyloc nuts, axle nuts, tube end caps, paint, reflectors, cable ties; two rated load and slope plates (150 x 30 mm, engraved aluminium or printed vinyl on steel), on the outside of the right rail and the inside of the left rail | Local market | 25.00 | buy | Estimate; plates about $3 added 2026-10-02 (local sign maker)
13 Optional SwapCell receiver | 1 | Vehicle receiver to latch class V1: side guides, over-centre preload lever (330 N), blind-mate receptacle, 10 kOhm INTERLOCK coding resistor | Self and connector distributor | 45.00 | make | Optional; bolts to the item 1 mounting plate; receptacle price from the SwapCell BOM
14 Tire tube and liner set | 4 | 26 x 2.1 to 2.4 in puncture-resistant tire, thorn-resistant tube, tire liner | Bicycle parts dealer | 24.00 | buy | Tire about $14, tube $6, liner $4
15 Parking lock pin | 1 | 10 mm ball-lock (detent) pin with pull ring and lanyard, about 140 mm long, through tabs with 10.5 mm holes welded to the inner and outer blades of the left rear fork; the pin passes through the skirt guard and the spokes so the wheel cannot turn, and ends inside the axle nuts | Local stockist and welder | 6.00 | make | Positive parking lock (WWK-DDR-002); outer tab added so the pin is held at both ends (WWK-DDR-003); the lever latch stays for short stops
16 Headset and steering lock set | 4 | 1 1/8 in external-cup (EC34) headset; 40 mm clamp collar with a welded 3 mm lock plate, 8.5 mm hole 45 mm from the steering axis; 8 mm steel lock pin with ring and R-clip, dropped through the plate into the pin guide on the frame (front: lifted out to let the caster swivel; rear: always in) | Bicycle parts dealer and welder | 8.00 | buy | Headset about $5, collar and plate $2, pin $1; same set at all four corners (WWK-DDR-003)
17 Hold-to-release brake | 1 | Bail lever clamped on the left grip tube (22.2 mm), 120 mm blade under the grip; spring unit: 26 mm steel tube 132 mm long with end caps, compression spring about 380 N preload and 10 N/mm, toggle and a cable yoke that lets either input pull both outputs; two saddle clips with M5 bolts to the tab on the left hip sleeve; bail cable and two drum cables with housing | Bicycle parts dealer, spring stockist and welder | 30.00 | make | Bail lever about $8 (long bicycle or mower-style lever), tube, caps and toggle about $8, spring about $4, yoke about $5, cables and housing about $5; decided by Amish 2026-10-02 (WWK-DEC-001)

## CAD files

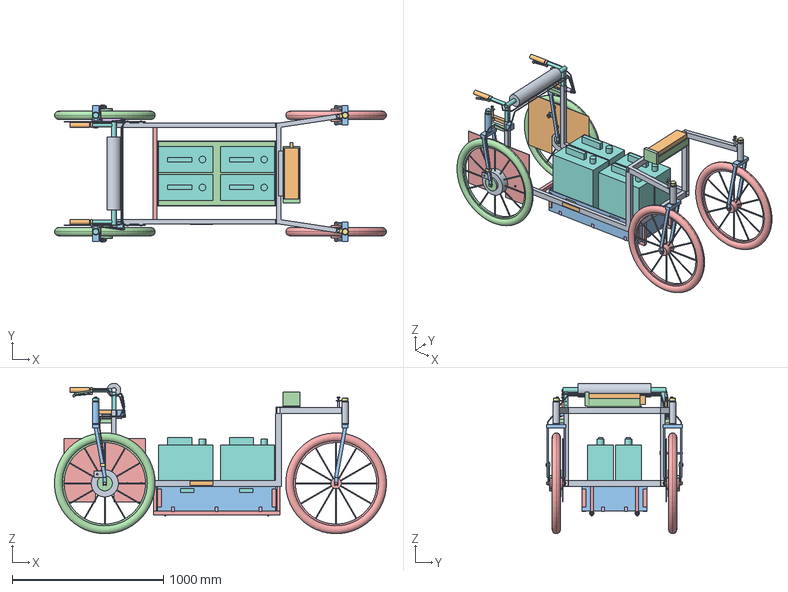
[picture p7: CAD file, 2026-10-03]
cad/step/waterwalker-assembly.step
2196.4 x 908.0 x 994.8 mm

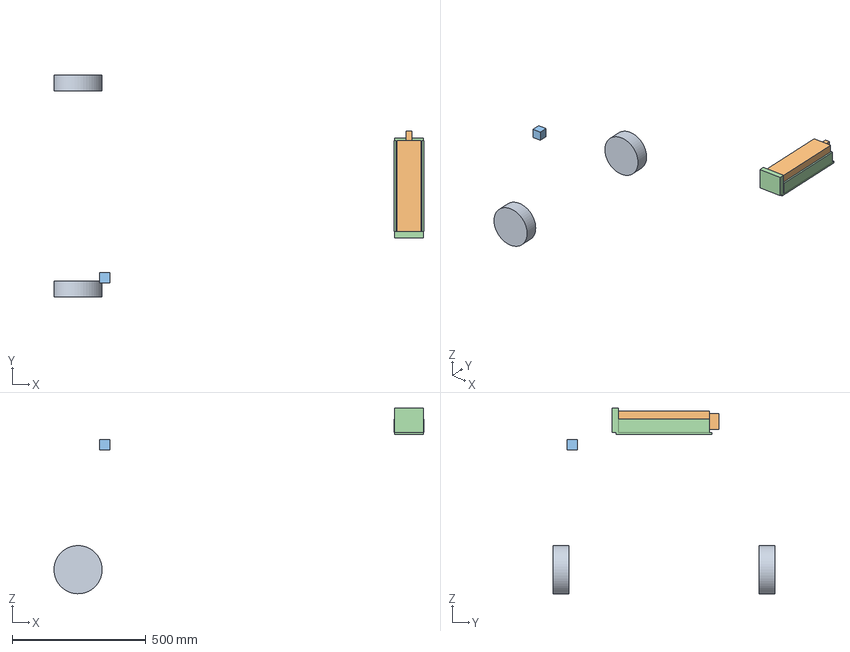
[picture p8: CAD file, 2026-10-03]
cad/step/waterwalker-assist-kit.step
1380.8 x 830.0 x 692.5 mm

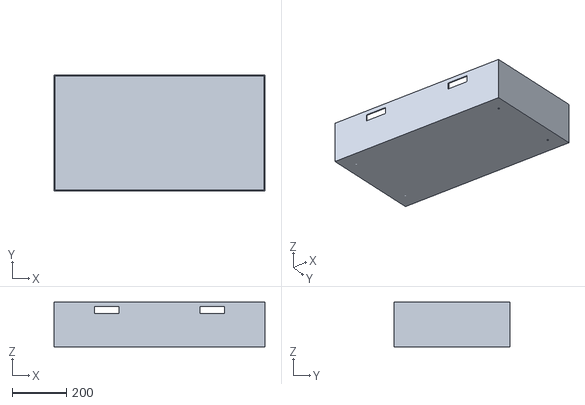
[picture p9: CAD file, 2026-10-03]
cad/stl/waterwalker-cradle.stl
780.0 x 430.0 x 166.0

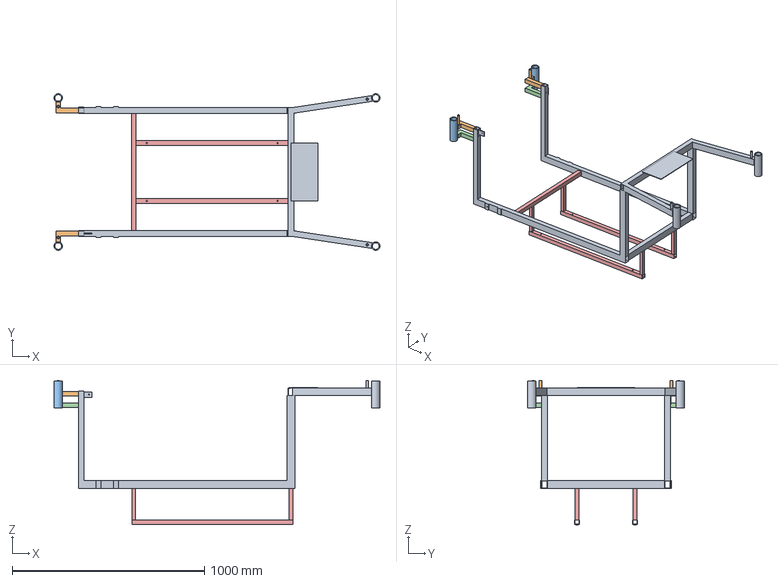
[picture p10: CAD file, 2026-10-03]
cad/step/waterwalker-frame.step
1694.0 x 814.0 x 749.0 mm

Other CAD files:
cad/step/waterwalker-first-prototype.step
cad/stl/waterwalker-assembly.stl
cad/stl/waterwalker-frame.stl

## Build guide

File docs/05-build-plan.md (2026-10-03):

---
doc_id: WWK-BLD-001
title: WaterWalker prototype build plan
project: WaterWalker
doc_type: Build plan
version: "0.2"
status: Draft
date: '2026-10-02'
author: Amish Chadha
license: CERN-OHL-S-2.0
revisions:
  - version: "0.1"
    date: '2026-10-02'
    author: Amish Chadha
    change: First build plan, with pictures by component and step; design made constructable (WWK-DDR-003)
  - version: "0.2"
    date: '2026-10-02'
    author: Amish Chadha
    change: Amish's decisions of 2026-10-02 carried in; hold-to-release brake (section 3.9, step 9, safety stop S4), torque-arm tabs on both rear forks, rating plates, cradle hand holds, weld inspection at every service; steps 9 to 11 renumbered 10 to 12
---

# WaterWalker prototype build plan

**Plan, not yet built.** How to build the first proof-of-concept prototype, component by component. Building and testing to it is TRL 4 work. Decisions still to be made are kept in the design decisions register ([docs/06-design-decisions.md](06-design-decisions.md)), not here.

## 1. What you are building

Figure 1. Every component, pulled apart and numbered in build order

*Figure 1. Every component pulled apart and numbered in build order.*

The prototype is the first WaterWalker without assist: a welded mild steel frame on four 26 in bicycle wheels, open at the rear so the user walks in between the rear wheels and pushes on a padded hip bar, with a plywood cradle between the axles for four 20 L jerrycans. Figure 1 shows the 15 components in the order you make or fit them. Nine are made: the frame weldment, the two rear head tube brackets, the cradle carrier, four lock collars, the tabs welded to the rear forks, two skirt guards, the hip bar, the spring unit of the hold-to-release brake and the cradle. The rest are bought bicycle parts and fixings: four rigid forks, four built wheels (drum hubs at the rear), headsets, tires, a brake lever with a parking latch, a bail lever, cables, grips, a hip pad, lock pins, two rating plates and bolts. The work is sawing, drilling, coping and arc welding square and round steel tube, cutting plywood and plastic sheet, and fitting bicycle parts. The parts cost about USD 492 from the bill of materials. The assist mounting points are built in; the assist kit itself is a later prototype.

> **Safety:** Loaded, the carrier weighs about 125 kg and rolls away on a slope if let go. Never load it before the safety stops of section 6 are passed, never leave it loaded on a slope without the parking lock pin in, and never carry a person in the cradle. Welding gives off fumes and ultraviolet light, and hot steel and sharp cut edges burn and cut: weld in a ventilated space with a welding helmet, gloves and cotton clothing, and deburr every cut. Steel fork blades must only be welded by a welder who has done it before, with short welds and no undercut.

## 2. What changed to make it buildable

The concept showed what the carrier does; many of its parts could not be made or fixed as drawn. Each change below keeps what the carrier does, and all of them are recorded in decision record WWK-DDR-003, which Amish accepted on 2026-10-02.

*Table 1. Changes from the concept.*

| Component | The concept had | The buildable design has | Why |
| --- | --- | --- | --- |
| Side rails | Rails running back through the rear forks to behind the axle | Rails ending at the hip sleeves, 45 mm ahead of the rear axle (Figure 2) | The forks now hold the rear wheels; the rear stays open |
| Rear head tubes | One short bracket per head tube, running into the tube; head tube straight above the axle | Two brackets 60 mm apart per head tube; head tube 60 mm behind the axle, matching the fork's offset (Figures 5 and 6) | Holds the twist from parking on one pinned wheel; any rigid fork fits |
| Cradle support | Hangers standing on the cradle floor, through its end walls; nothing under the floor | Two steel bearers under the floor on four hangers from the cross members (Figures 7 and 8) | The floor rests on steel; the cradle lifts out after four bolts |
| Rear cross member | Through the rear jerrycans | 17.5 mm further back, just behind the cradle | The cans clear it by 8 mm |
| Caster arms | Into the centre of the head tube, on stubs outboard of the risers | Straight from the top of each riser to the side of the head tube, angled 8.6 degrees outward (Figures 2 and 3) | The steerer passes freely; the arm's load goes straight down the riser |
| Forks in the head tubes | Solid head tubes; a lock pin standing in the air | Headsets at all four corners; a lock collar and pin on each fork (Figures 9 and 10) | The forks are held, turn freely at the front and are pinned straight at the rear |
| Hip bar | Posts 280 mm long in solid sleeves; 32 mm grip tubes | 364 mm posts sliding in tube sleeves; 22.2 mm grip tubes (Figures 16 and 17) | 150 mm stays in the sleeve at full height; standard grips and brake lever fit |
| Parking lock pin | Held by one tab only | Held by tabs on both fork blades (Figures 11 and 12) | The pin no longer bends under the parking load |
| Skirt guards | No fixing; a round hub hole | Two bolts to rail tabs, two clips on the fork blade, a slot for the hub (Figures 14 and 15) | Fitted before the wheel; held at four points |
| Brake reaction arm | Ending in the air | Clipped along the outer fork blade (Figure 13) | It must carry the brake torque |
| Cradle | Walls overlapping, no fixings | End walls between the side walls; 14 angle brackets outside (Figures 18 and 19) | 4 mm plywood takes no screws in its edge |

Amish's decisions of 2026-10-02 then added four things that the concept did not have: a hold-to-release brake (a bail under the left grip, a spring unit on the left hip sleeve and cables to both rear drums; section 3.9), a torque-arm tab on the left rear fork as well as the right, so that a later two-motor assist kit bolts on (section 3.5), two rated load and slope plates on the rails, and two hand holds in each cradle side wall (section 3.8).

## 3. Making the components

Make and check each component before the assembly step that needs it. Sizes are in millimetres. Heights are above the ground with the carrier on its wheels; "ahead of the rear axle" is measured forward from the rear axle line; "out from the centre line" is measured sideways. "Left" and "right" are as the user sees them, walking in. Workshop tolerance is 1 mm on steel and 2 mm on plywood unless a step says otherwise; drawings do not carry tolerances before TRL 4.

### 3.1 Frame weldment

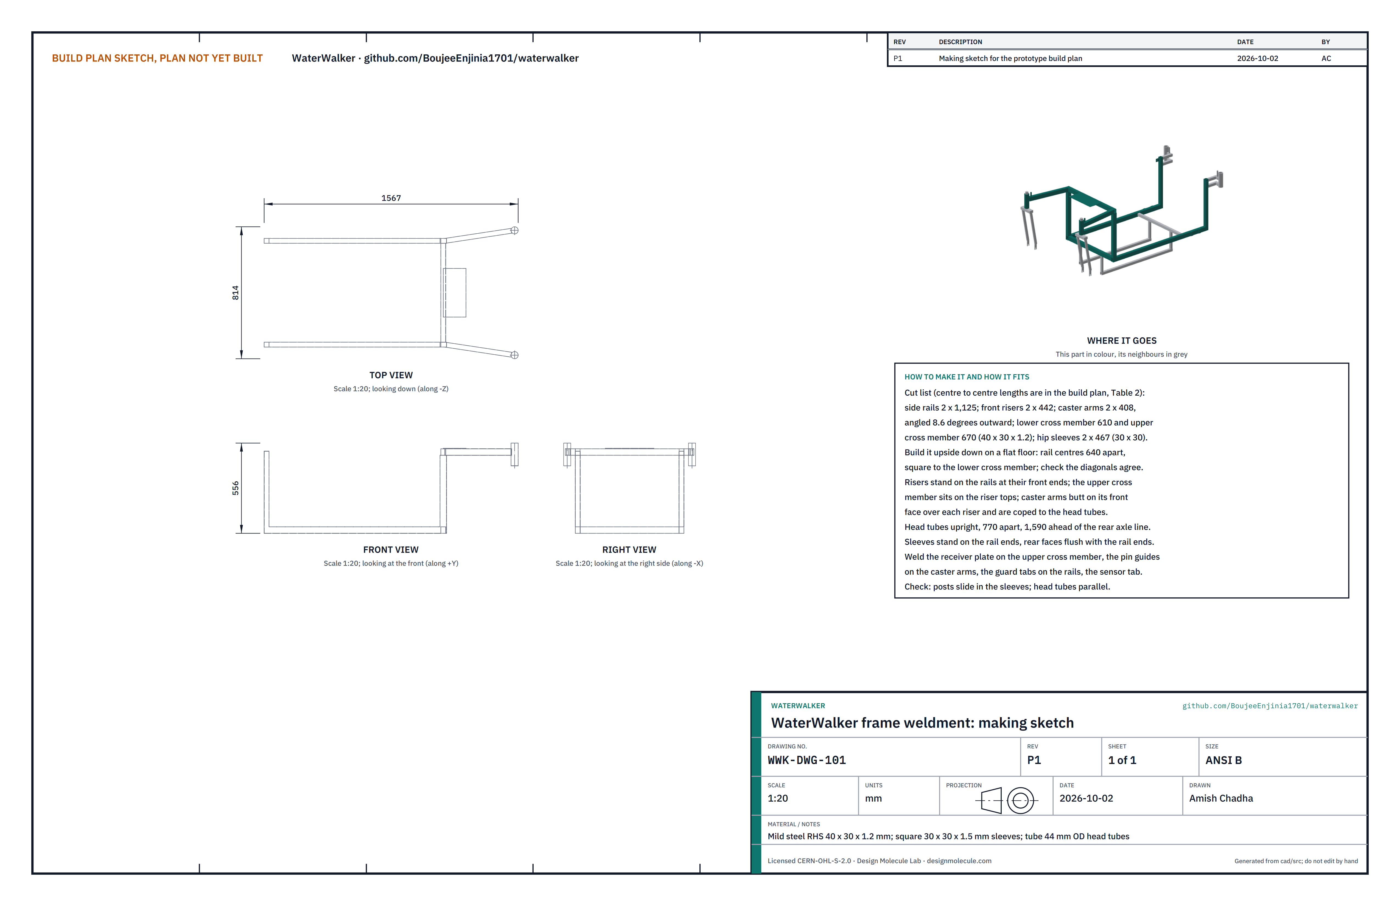
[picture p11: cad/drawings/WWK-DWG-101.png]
Figure 2. Making sketch of the frame weldment


*Figure 2. Frame weldment making sketch (WWK-DWG-101).*

**What it is and what it is made from.** The welded steel ladder that carries everything: two side rails, two front risers, a lower and an upper front cross member, two caster arms, two hip sleeves and the two front head tubes, with small plates and tabs welded on. Mild steel rectangular tube 40 x 30 x 1.2 mm, square tube 30 x 30 x 1.5 mm for the sleeves, and tube 44 mm outside and 34 mm bore for the head tubes.

*Table 2. Cut list for the frame, the rear brackets and the cradle carrier (lengths along the centre line).*

| Piece | Tube | Number | Length | Ends |
| --- | --- | --- | --- | --- |
| Side rail | 40 x 30 x 1.2 | 2 | 1,125 | Square |
| Front riser | 40 x 30 x 1.2 | 2 | 442 | Square |
| Front lower cross member | 40 x 30 x 1.2 | 1 | 610 | Square |
| Upper cross member | 40 x 30 x 1.2 | 1 | 670 | Square |
| Caster arm | 40 x 30 x 1.2 | 2 | 408 | Mitred 8.6 degrees at the root; coped to the 44 mm head tube |
| Hip sleeve | 30 x 30 x 1.5 | 2 | 467 | Square |
| Front head tube | 44 OD, 34 bore | 2 | 140 | Faced square |
| Rear head tube | 44 OD, 34 bore | 2 | 140 | Faced square |
| Rear bracket arm | 25 x 25 x 1.5 | 4 | 117.5 | Square |
| Rear bracket stub | 25 x 25 x 1.5 | 4 | 30.5 | One end coped to the head tube |
| Rear cross member | 25 x 25 x 1.5 | 1 | 610 | Square |
| Cradle bearer | 25 x 25 x 1.5 | 2 | 837.5 | Square |
| Rear hanger | 20 x 20 x 1.5 | 2 | 171 | Square |
| Front hanger | 20 x 20 x 1.5 | 2 | 164 | Square |

**How to make it.**

1. Cut every piece in Table 2 and deburr it. Mark each piece with chalk.
2. Lay the two side rails on a flat floor, 640 apart centre to centre and parallel. Weld the front lower cross member between their front ends, square, its front face flush with the rail ends. Check the diagonals agree within 2 mm.
3. Stand a front riser on the top of each rail at its front end, flush with the rail's end and sides, square both ways. Tack, check, weld.
4. Lay the upper cross member across the riser tops, centred, its ends 15 out past each riser. Weld it on.
5. Jig each front head tube upright, 385 out from the centre line and 1,590 ahead of the rear axle line (440 ahead of the risers' centre), its bottom 730 above the ground (use blocks under the rails at the 313.5 rail bottom height). Fit each caster arm between the front face of the upper cross member over its riser and the side of its head tube; the arm angles 8.6 degrees outward. Cope the head tube end until it sits fully on the tube wall. Weld.
6. Stand a hip sleeve on the top of each rail at its rear end, rear face flush with the rail end, square both ways. Weld only the outside corners first, then check that a hip post slides in; file out any weld that has pulled the bore in.
7. Weld on the small parts: the receiver plate (140 x 300 x 3) on top of the upper cross member, lapping its front face by 15 and centred; a pin guide (14 mm tube, 39 long) upright on each caster arm, 45 back along the arm from the head tube axis, after drilling a 9 mm hole in the arm top under it; two guard tabs (25 x 5 flat bar, 40 long) flat on the outer face of each rail at 150 and 240 ahead of the rear axle line, then drilled 5 and tapped M6 through tab and rail wall; the sensor tab (40 x 30 x 4) standing forward from the right sleeve's front face, 785 to 815 up, with a 6.5 hole; the spring unit tab (28 x 50 x 4) flat on the outer face of the left sleeve, centred 775 up, drilled and tapped M5 at 53 and 67 ahead of the rear axle line for the saddle clips of section 3.9.
8. Drill a 6.5 hole front to back through each sleeve, 775 up, for the height pin.
9. Fit plastic end caps in every open tube end.
10. After painting, stick or rivet the two rated load and slope plates (150 x 30) to the rails, centred 640 ahead of the rear axle line: one on the outer face of the right rail and one on the inner face of the left rail, where the user reads it when walking in.

**How it fits the parts next to it.** The rear head tube brackets weld to the rear faces of the hip sleeves (section 3.2); the cradle carrier hangs from the front lower cross member and the rear cross member (section 3.3); the forks go up through the head tubes (step 2 and 5); the hip posts slide into the sleeves (section 3.7). The joints at the front corner:

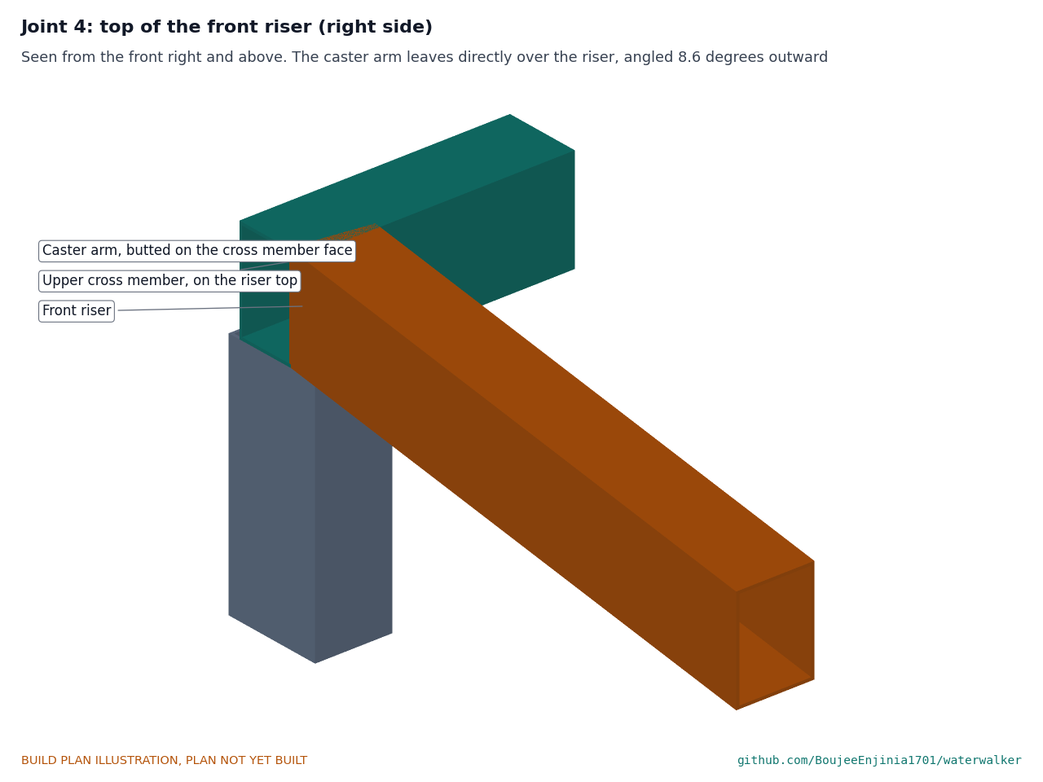
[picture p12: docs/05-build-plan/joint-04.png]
Figure 3. Joint 4: top of the front riser


*Figure 3. Joint 4. The upper cross member sits on the riser top; the caster arm butts on the cross member's front face directly over the riser.*

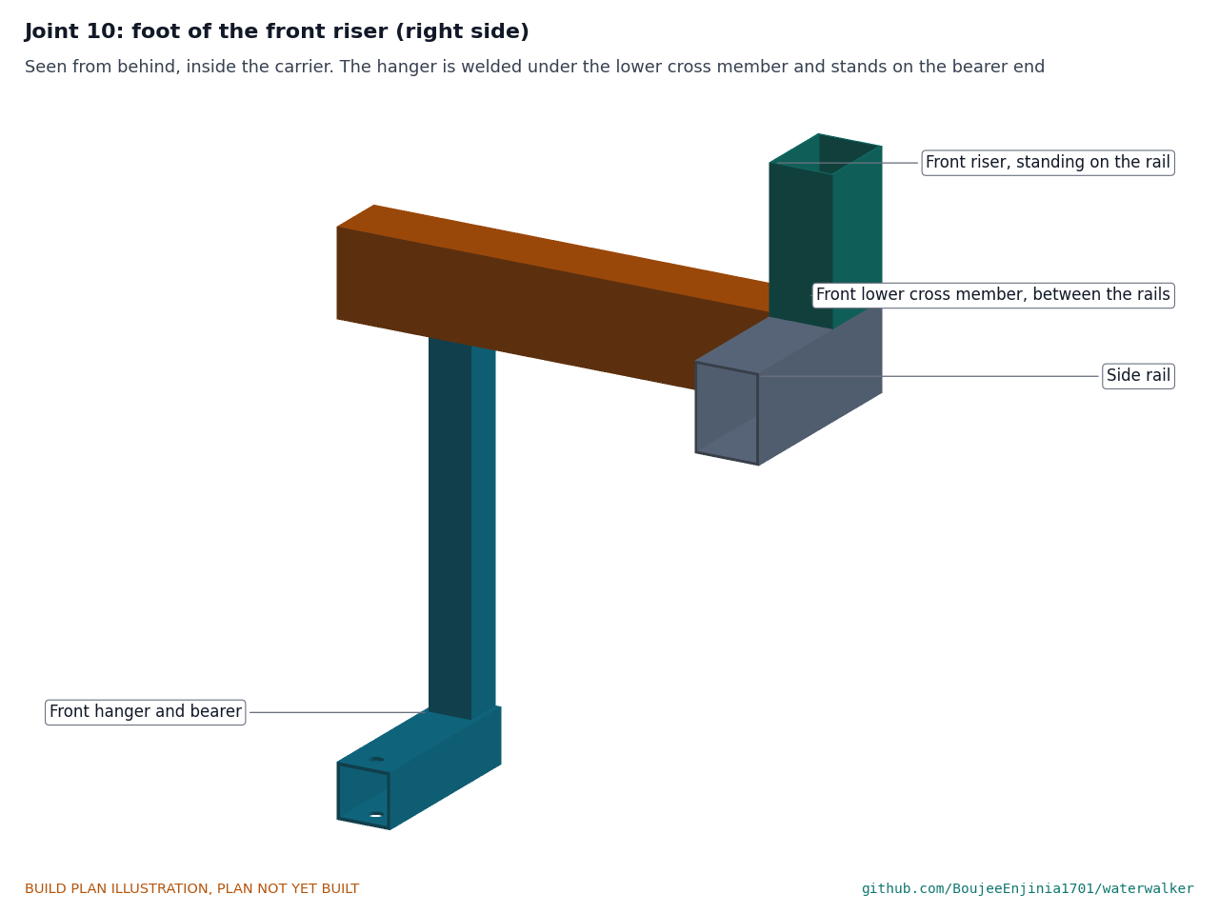
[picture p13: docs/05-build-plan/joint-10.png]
Figure 4. Joint 10: foot of the front riser


*Figure 4. Joint 10. The riser stands on the rail; the lower cross member fits between the rails.*

**Check before moving on.** The rails are parallel and level; the four head tube positions are within 1 mm; each head tube is upright within 0.5 degree both ways; both hip posts slide in and out of their sleeves by hand.

### 3.2 Rear head tubes and brackets (make 2, mirror images)

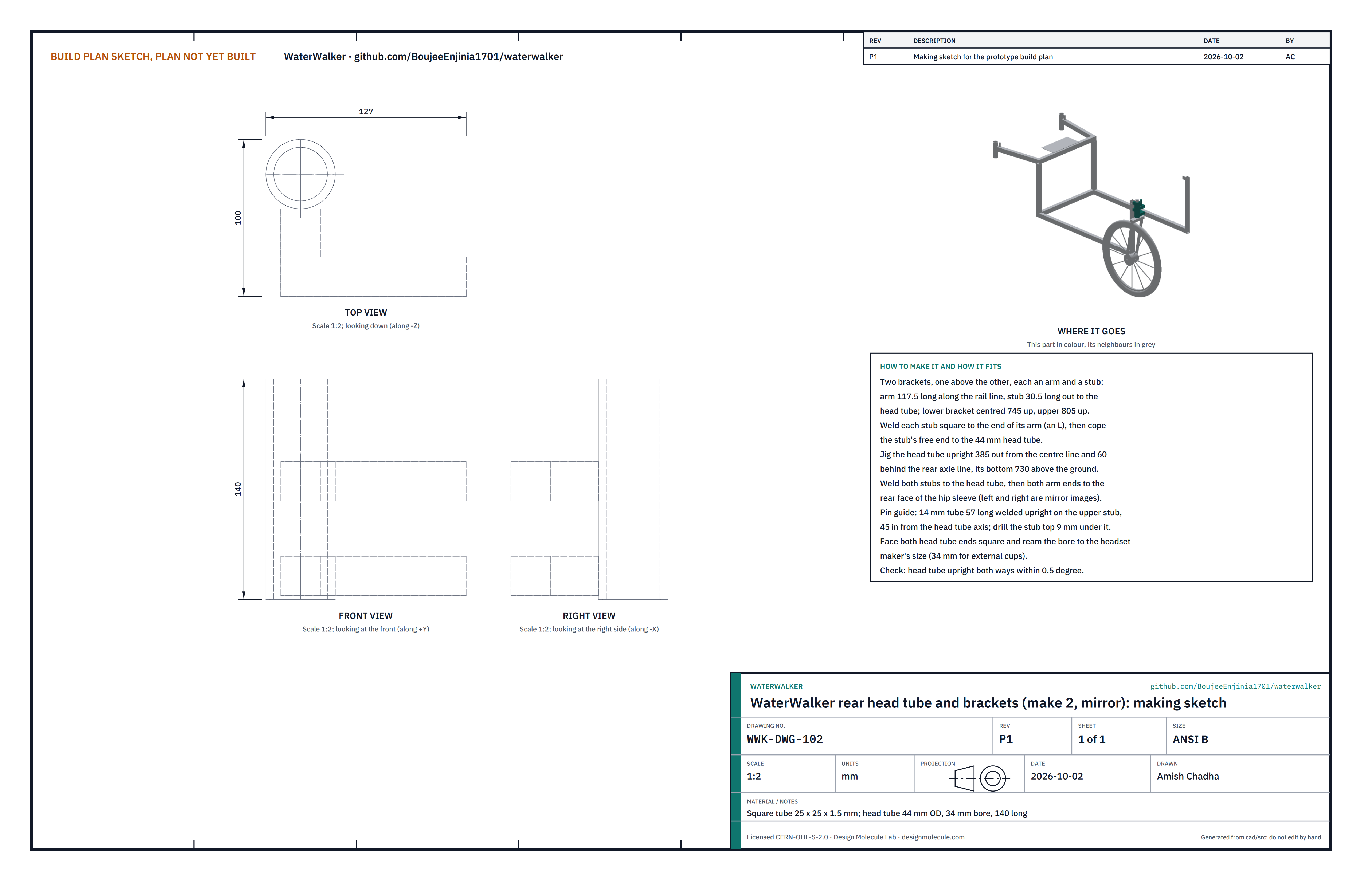
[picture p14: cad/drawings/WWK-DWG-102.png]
Figure 5. Making sketch of the rear head tube and brackets


*Figure 5. Rear head tube and brackets making sketch (WWK-DWG-102).*

**What it is and what it is made from.** The head tube that holds each rear fork, carried on two short brackets welded to the back of the hip sleeve. Square tube 25 x 25 x 1.5 mm and the same 44 mm head tube as the front.

**How to make it.**

1. For each bracket, weld a stub square to one end of an arm to make an L, with the stub's free end pointing outward. Cope the stub's free end to fit the 44 mm head tube.
2. Jig the head tube upright, 385 out from the centre line and 60 behind the rear axle line, its bottom 730 above the ground.
3. Offer up the lower bracket (centre 745 up) and the upper bracket (centre 805 up): each arm runs along the rail's centre line to the sleeve's rear face, each stub meets the head tube. Weld the stubs to the head tube, then the arms to the sleeve.
4. Weld a pin guide (14 mm tube, 57 long) upright on top of the upper stub, 45 in from the head tube axis, after drilling a 9 mm hole in the stub top under it.
5. Face both head tube ends square and ream the bore to the headset maker's size.

**How it fits the parts next to it.**

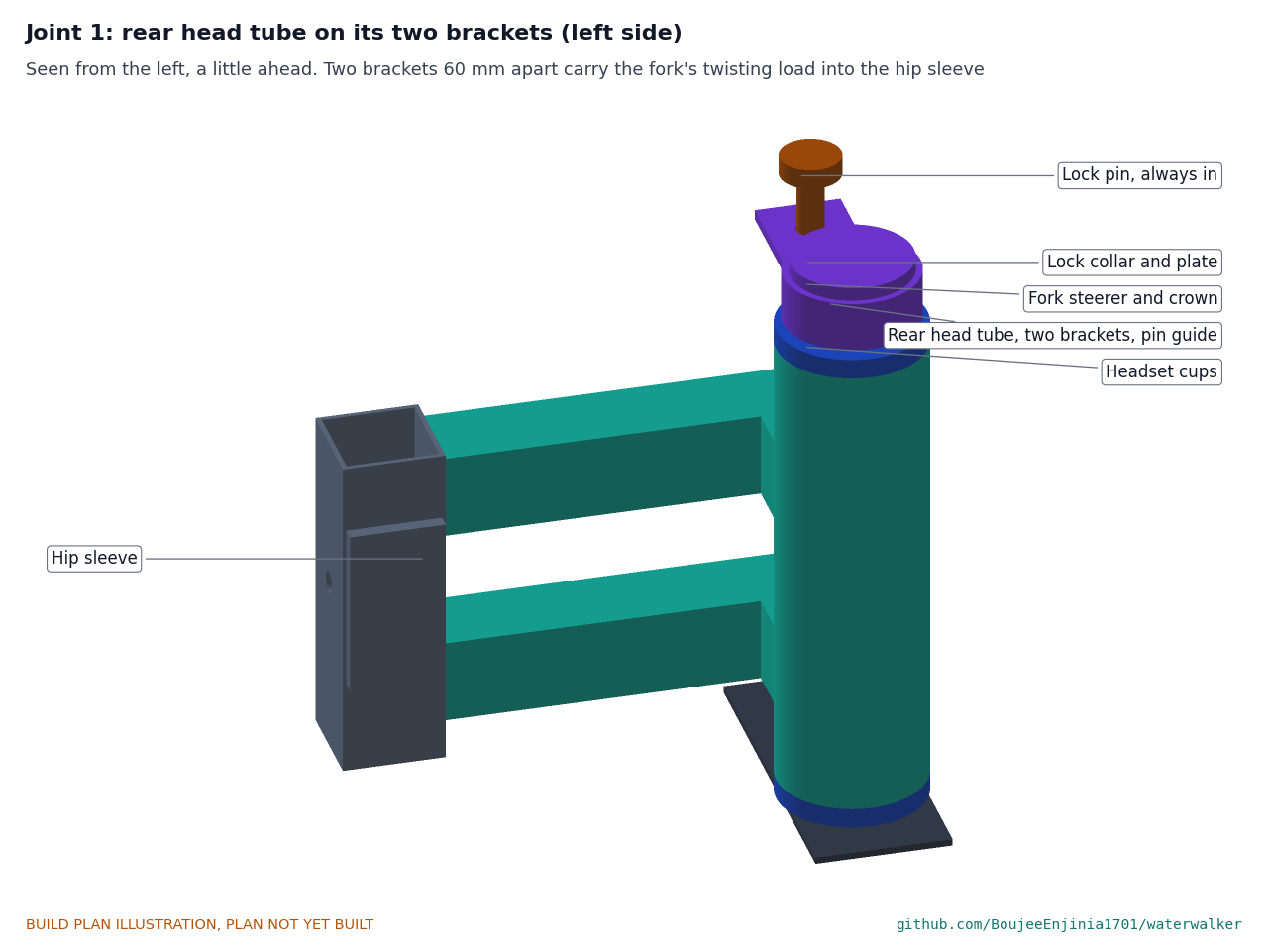
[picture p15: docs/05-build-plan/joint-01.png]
Figure 6. Joint 1: rear head tube on its two brackets


*Figure 6. Joint 1. The two brackets, 60 apart, turn the twist from the fork into push and pull on the sleeve.*

The arms butt on the sleeve's rear face and are welded all round. The stubs are coped to the head tube and welded all round. The fork crown passes 8 mm under the lower bracket.

**Check before moving on.** The head tube is upright both ways within 0.5 degree, 770 from the other rear head tube centre to centre, and lines up with the front head tube on the same side when sighted along the carrier.

### 3.3 Rear cross member and cradle carrier

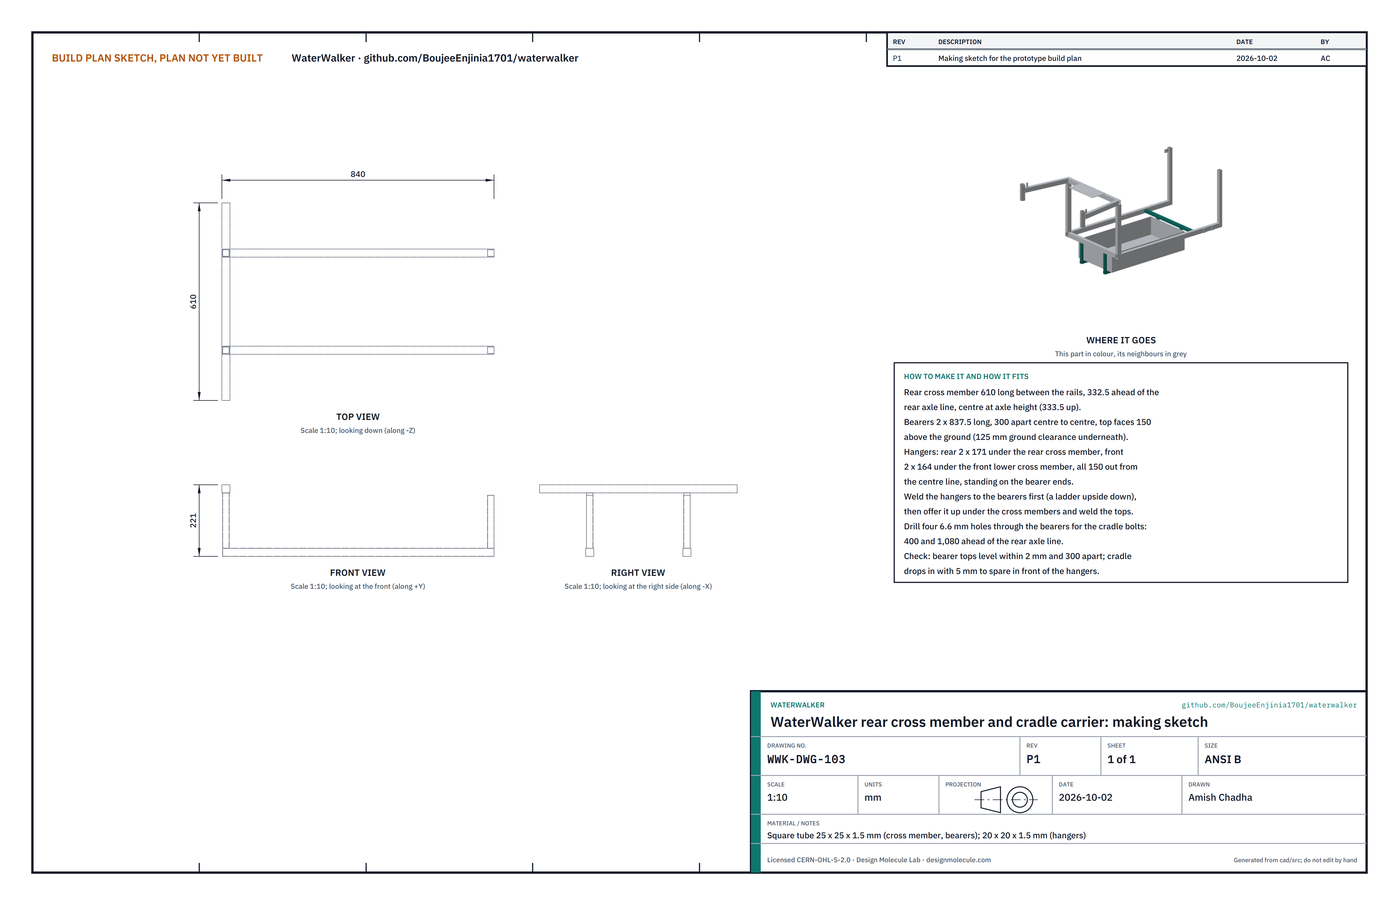
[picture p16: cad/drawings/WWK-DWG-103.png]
Figure 7. Making sketch of the cradle carrier


*Figure 7. Rear cross member and cradle carrier making sketch (WWK-DWG-103).*

**What it is and what it is made from.** The rear cross member between the rails, and a ladder under the cradle: two bearers the cradle floor rests on and four hangers that carry them from the cross members. Square tube 25 x 25 x 1.5 mm and 20 x 20 x 1.5 mm.

**How to make it.**

1. Weld the rear cross member between the rails, 332.5 ahead of the rear axle line, centred on the rail height.
2. Weld a rear hanger (171) standing on one end of each bearer, and a front hanger (164) on the other end, flush with the bearer ends. Keep them square.
3. Drill two 6.6 holes through each bearer, top to bottom, 400 and 1,080 ahead of the rear axle line once fitted (77.5 and 757.5 from the bearer's rear end).
4. Turn the frame upside down. Offer each bearer up so its hangers sit under the rear and front lower cross members, 150 out from the centre line. Weld the hanger tops all round.

**How it fits the parts next to it.**

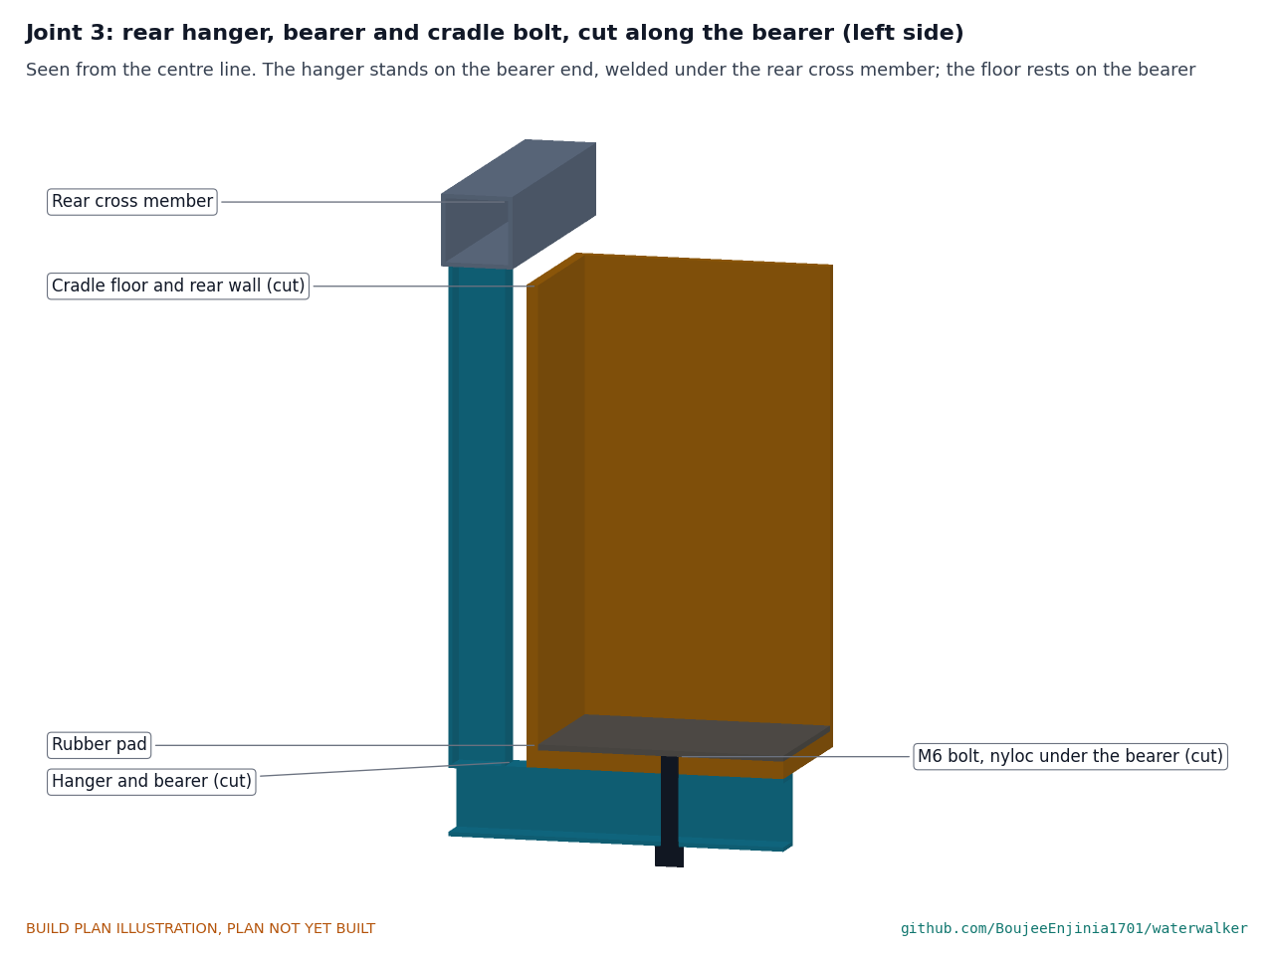
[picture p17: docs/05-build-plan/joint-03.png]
Figure 8. Joint 3: rear hanger, bearer and cradle bolt


*Figure 8. Joint 3. The hanger stands on the bearer end and is welded under the rear cross member; the cradle floor rests on the bearer and is bolted through it.*

The bearer tops are 150 above the ground; the cradle floor sits on them. The cradle clears the rear hangers by 5 and the front hangers by 10. Ground clearance under the bearers is 125.

**Check before moving on.** Both bearer tops are level within 2 mm and 300 apart; a straight edge across them touches both.

### 3.4 Lock collars (make 4)

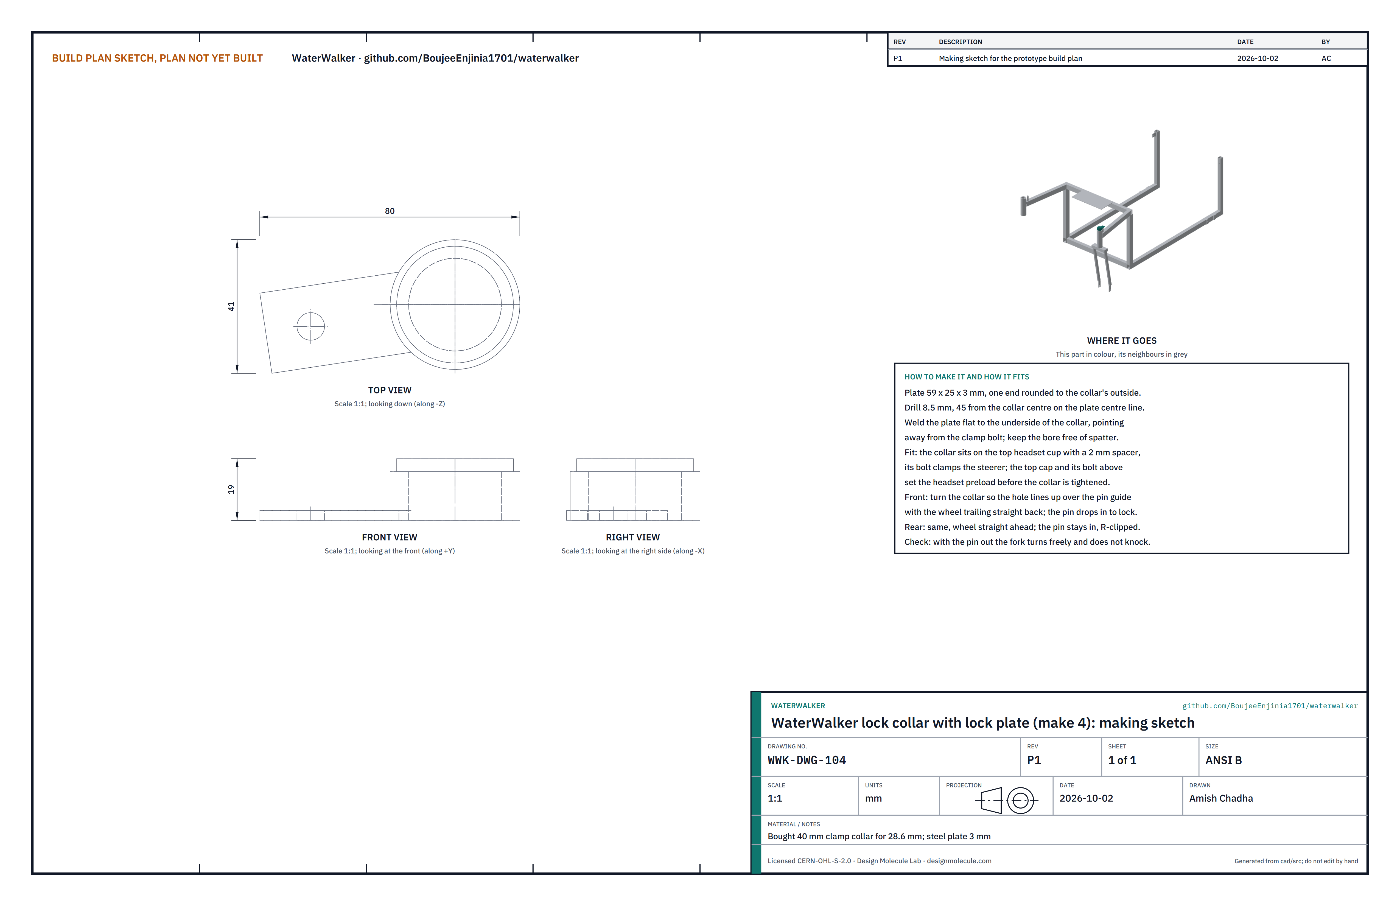
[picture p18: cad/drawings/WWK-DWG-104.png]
Figure 9. Making sketch of the lock collar


*Figure 9. Lock collar making sketch (WWK-DWG-104).*

**What it is and what it is made from.** A clamp collar on the top of each fork's steerer with a plate that a pin drops through, so the fork can be locked straight. A bought 40 mm clamp collar for a 28.6 mm steerer and 3 mm steel plate.

**How to make it.**

1. Cut four plates 59 x 25 from 3 mm plate; round one end to the collar's outside.
2. Drill an 8.5 hole on the plate's centre line, 45 from the collar centre.
3. Weld each plate flat to the underside of its collar, pointing away from the clamp bolt. Keep spatter out of the bore.

**How it fits the parts next to it.**

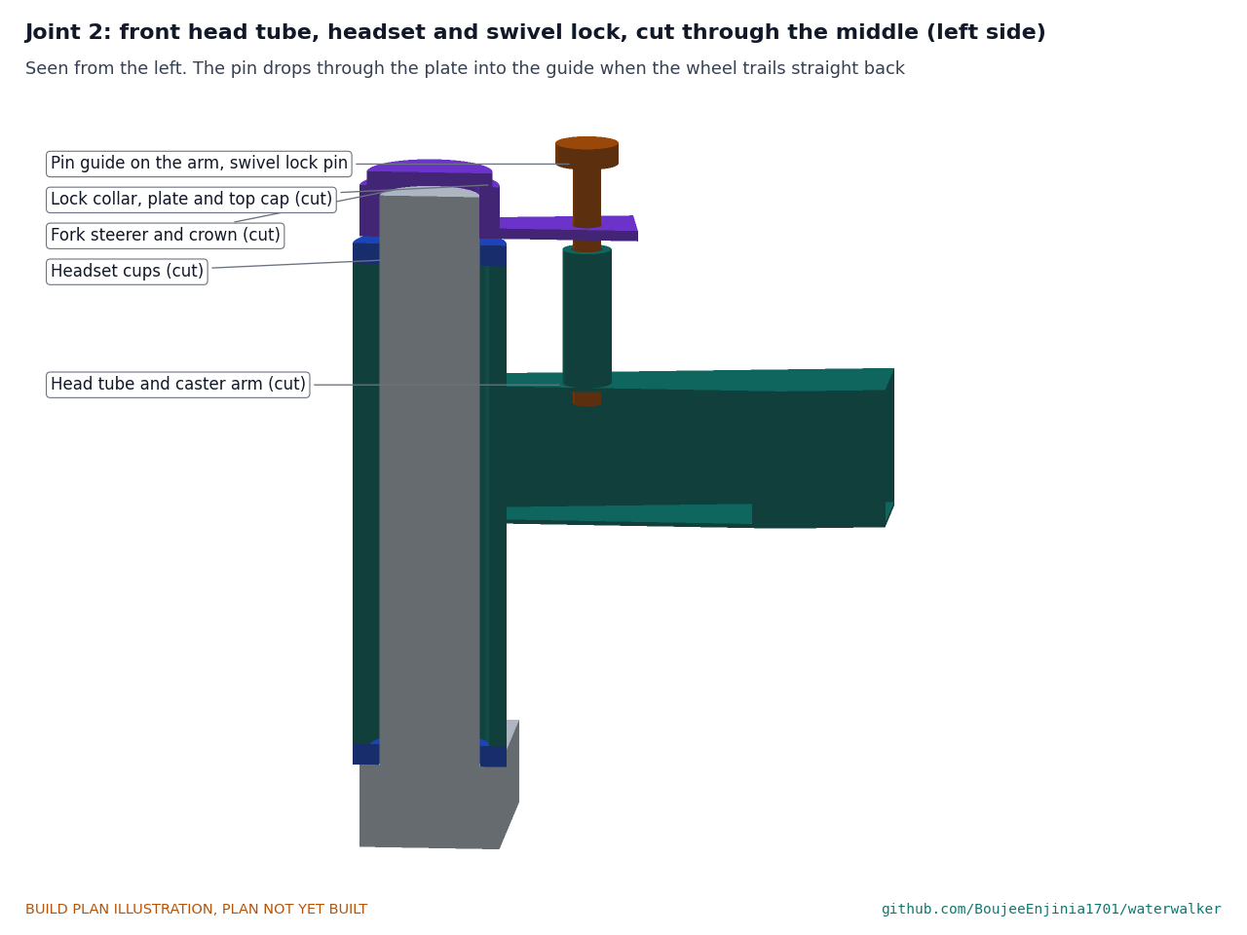
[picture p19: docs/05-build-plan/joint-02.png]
Figure 10. Joint 2: front head tube, headset and swivel lock


*Figure 10. Joint 2. The collar clamps the steerer 2 mm above the top headset cup; the top cap above it sets the headset preload; the pin drops through the plate into the guide on the caster arm.*

**Check before moving on.** With a collar on a spare steerer, an 8 mm pin passes through the plate hole freely.

### 3.5 Rear forks: welded tabs

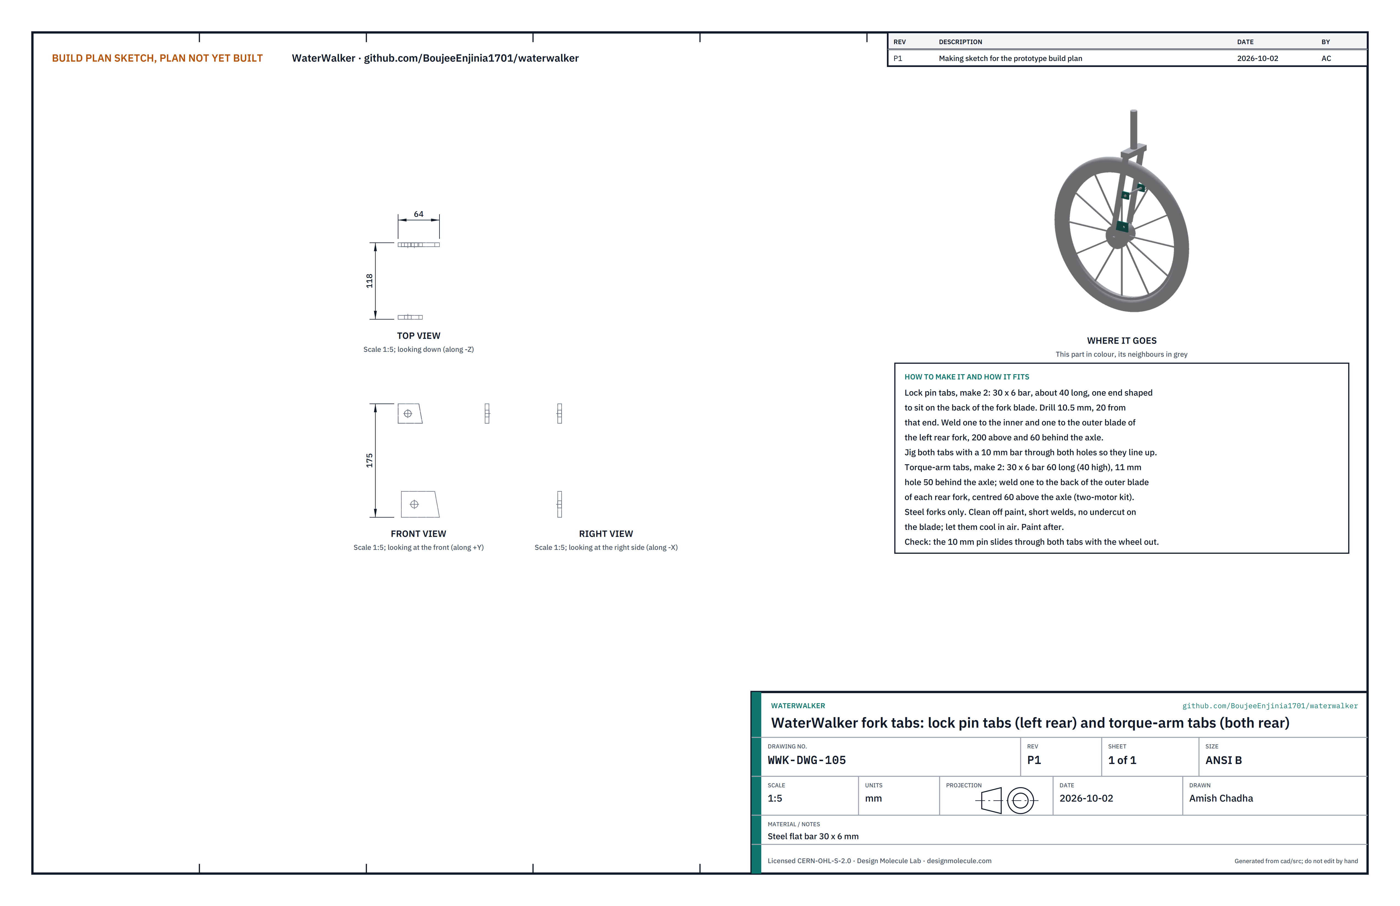
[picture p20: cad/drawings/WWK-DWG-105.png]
Figure 11. Making sketch of the fork tabs


*Figure 11. Fork tabs making sketch (WWK-DWG-105).*

**What it is and what it is made from.** Two tabs on the left rear fork that hold the parking lock pin at both ends, and one tab on each rear fork for the torque arms of the two hub motors of the later assist kit. Steel flat bar 30 x 6 mm, welded to bought steel forks.

**How to make it.**

1. Lock pin tabs: cut two pieces about 40 long. Shape one end of each to sit on the back of the fork blade. Drill 10.5, 20 from that end.
2. Strip the paint from the backs of the left rear fork's blades, 190 to 220 above the axle centre.
3. Put a 10 mm bar through both tabs and hold them on the backs of the inner and outer blades, the holes 200 above and 60 behind the axle centre. Weld with short runs, letting the blade cool between them.
4. Torque-arm tabs: cut two pieces 66 long, drill 11 at 50 behind the axle once fitted, and weld one to the back of each rear fork's outer blade, centred 60 above the axle and in the blade's thickness. On the left fork it sits 140 below the outer lock pin tab.
5. Paint the bare steel.

**How it fits the parts next to it.**

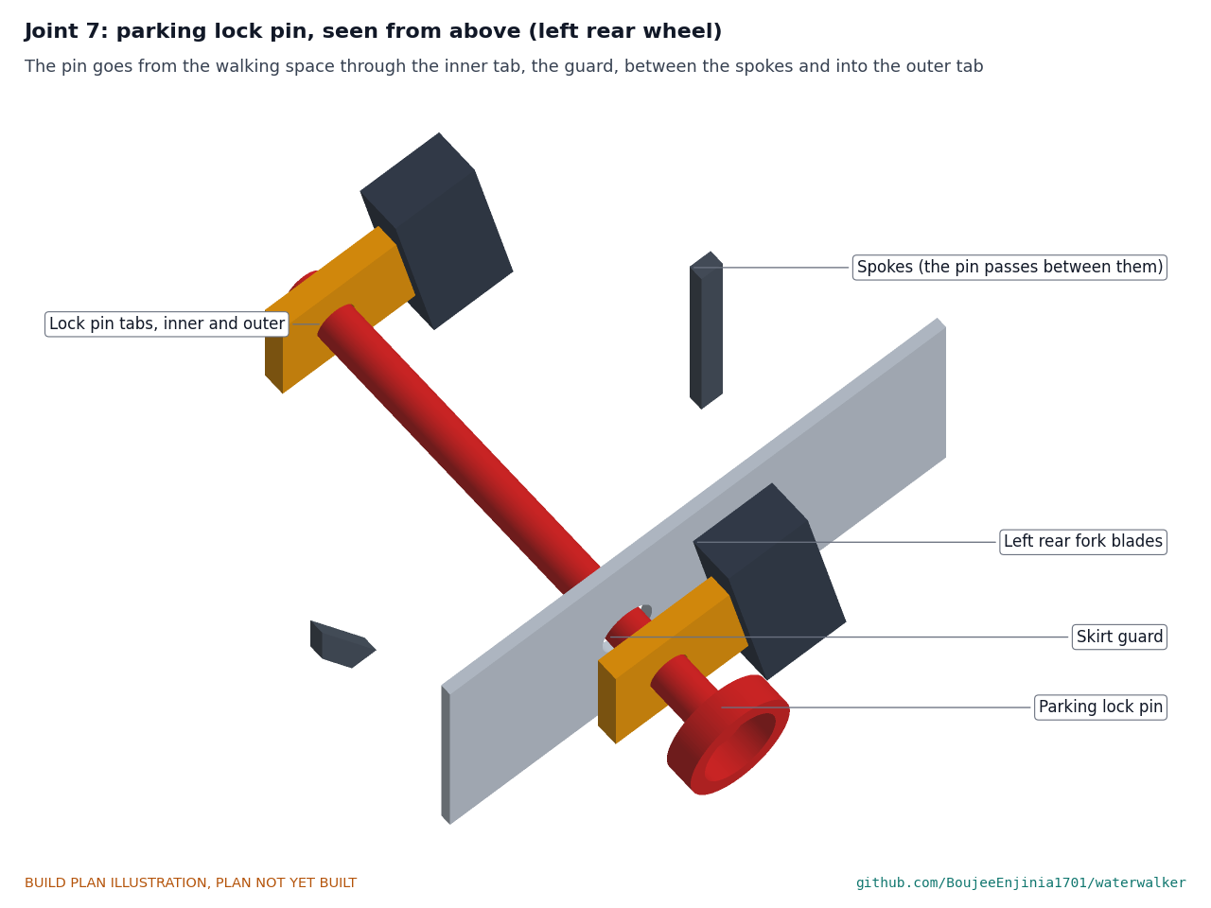
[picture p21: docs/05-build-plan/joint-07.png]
Figure 12. Joint 7: parking lock pin, seen from above


*Figure 12. Joint 7. The pin passes through the inner tab, the skirt guard and the spokes, and into the outer tab.*

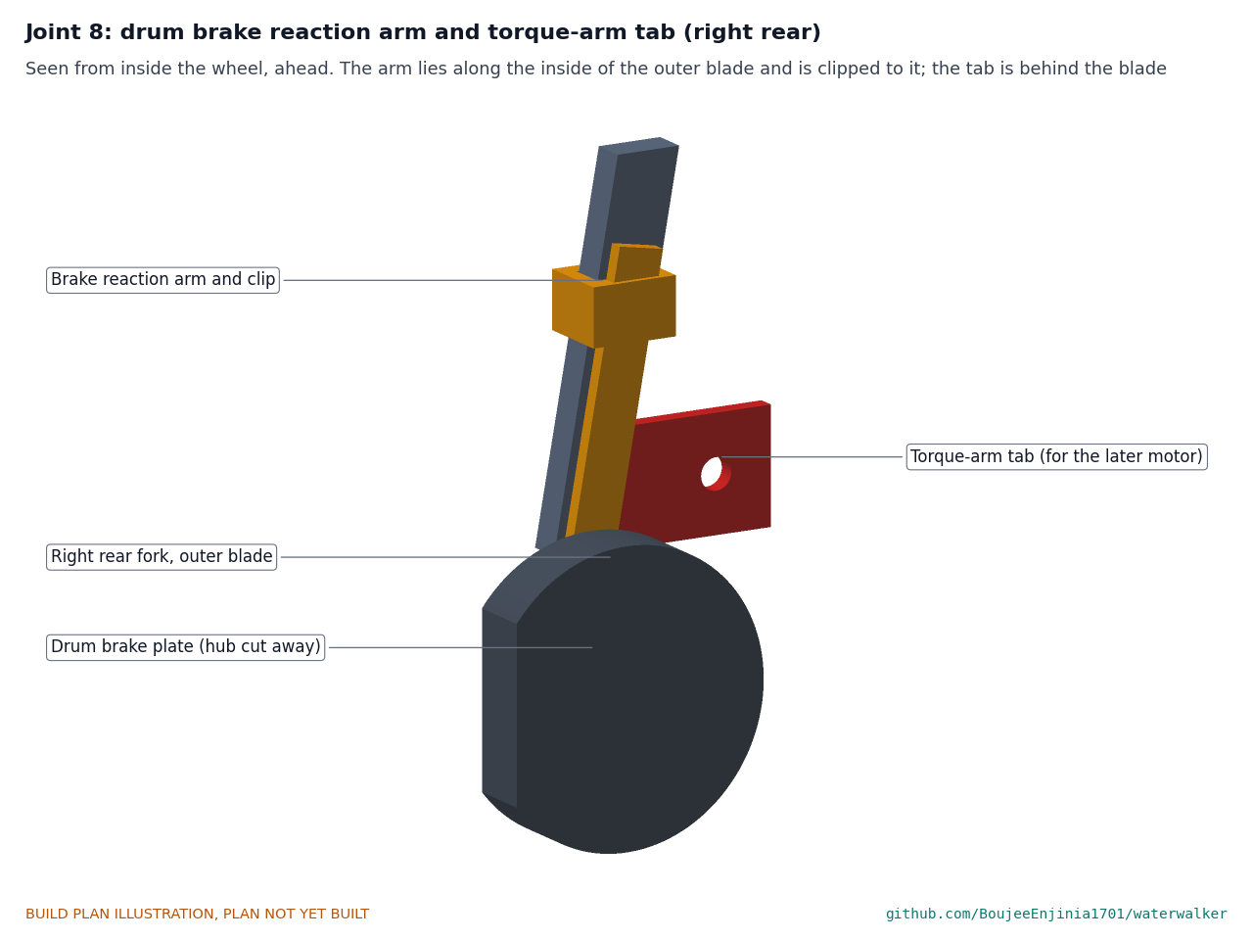
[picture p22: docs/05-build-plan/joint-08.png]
Figure 13. Joint 8: brake reaction arm and torque-arm tab


*Figure 13. Joint 8. The torque-arm tab sits behind the outer blade, clear of the drum brake's reaction arm (right fork shown; the left is its mirror image).*

**Check before moving on.** The 10 mm bar slides through both lock pin tabs without force; both torque-arm holes are at the same height; no crack shows at any weld under a bright lamp.

### 3.6 Skirt guards (make 2, mirror images)

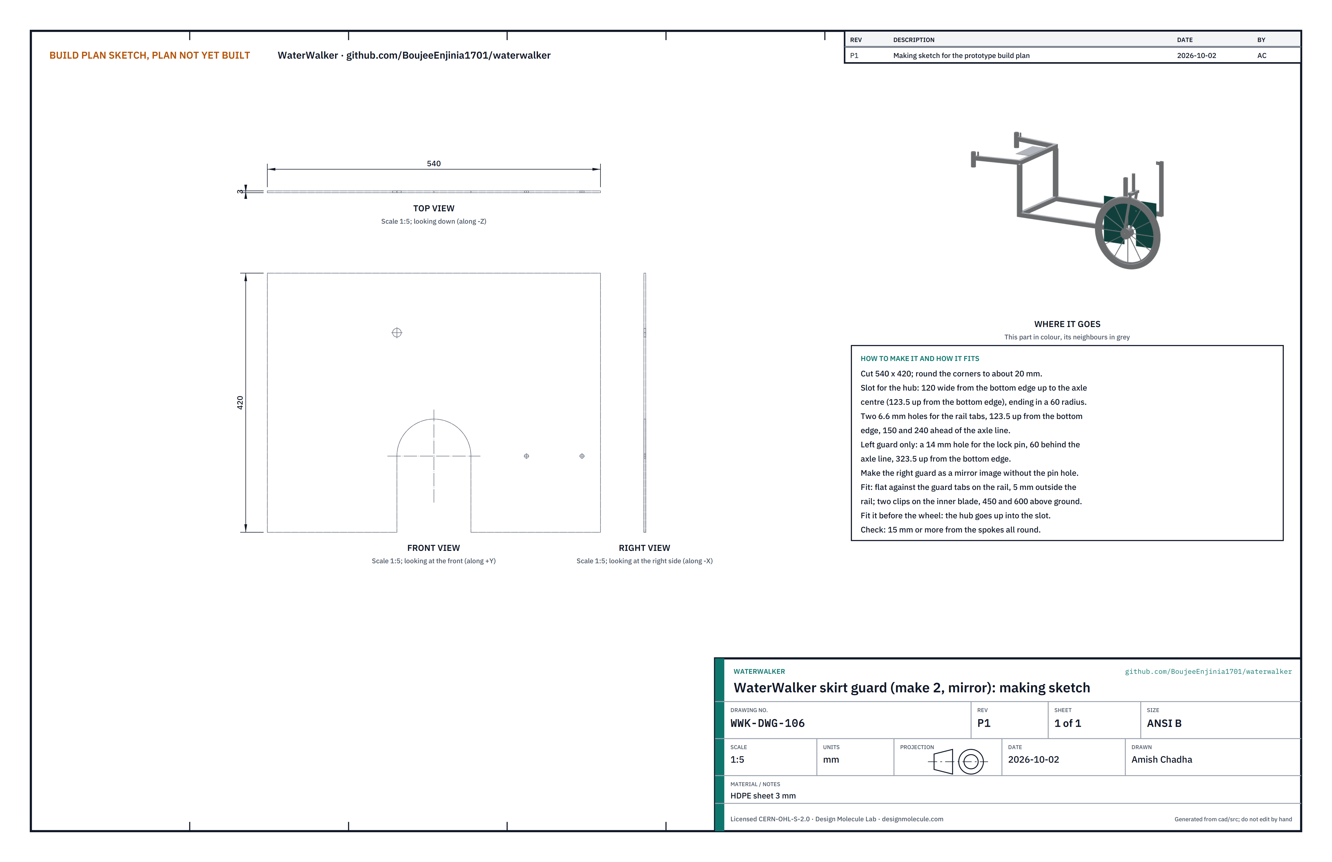
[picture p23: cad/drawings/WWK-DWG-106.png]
Figure 14. Making sketch of the skirt guard


*Figure 14. Skirt guard making sketch (WWK-DWG-106).*

**What it is and what it is made from.** A plastic sheet between each rear wheel's spokes and the walking space, so skirts, wraps and hands stay out of the spokes. HDPE sheet 3 mm.

**How to make it.**

1. Cut 540 x 420; round the corners to about 20.
2. Cut the hub slot: 120 wide, from the bottom edge up to the axle centre (123.5 up), finished with a 60 radius. The axle centre is 270 from the guard's rear edge.
3. Drill two 6.6 holes 123.5 up, at 150 and 240 ahead of the axle line, for the rail tabs.
4. Left guard only: drill a 14 hole for the lock pin, 60 behind the axle line and 323.5 up from the bottom edge.

**How it fits the parts next to it.**

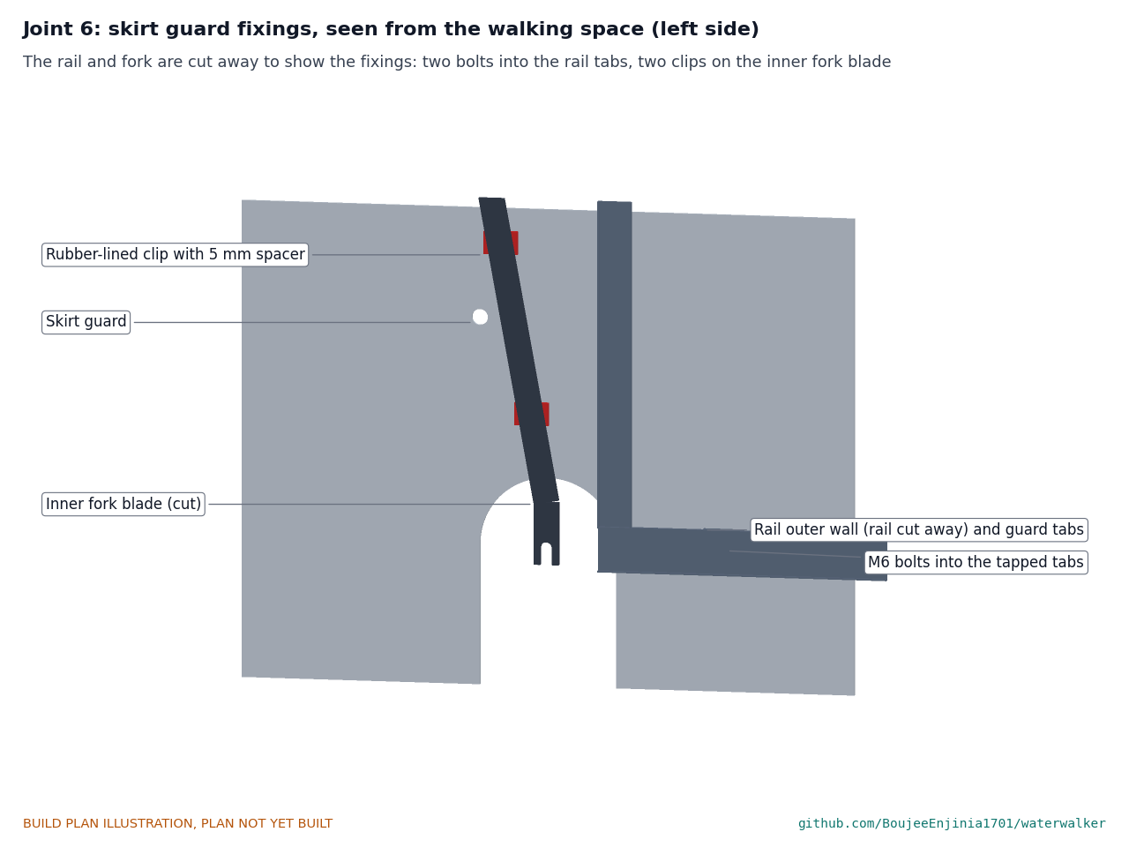
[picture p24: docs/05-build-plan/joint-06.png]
Figure 15. Joint 6: skirt guard fixings


*Figure 15. Joint 6. Two M6 bolts into the tapped rail tabs; two rubber-lined clips with 5 mm spacers on the inner fork blade.*

The guard lies flat against the two tabs, 5 outside the rail, and 15 from the spokes. The clips go round the inner fork blade 450 and 600 above the ground. The guard goes on before the wheel; the hub rises into the slot.

**Check before moving on.** The guard is flat, with no cracks at the slot corners or holes.

### 3.7 Hip bar weldment

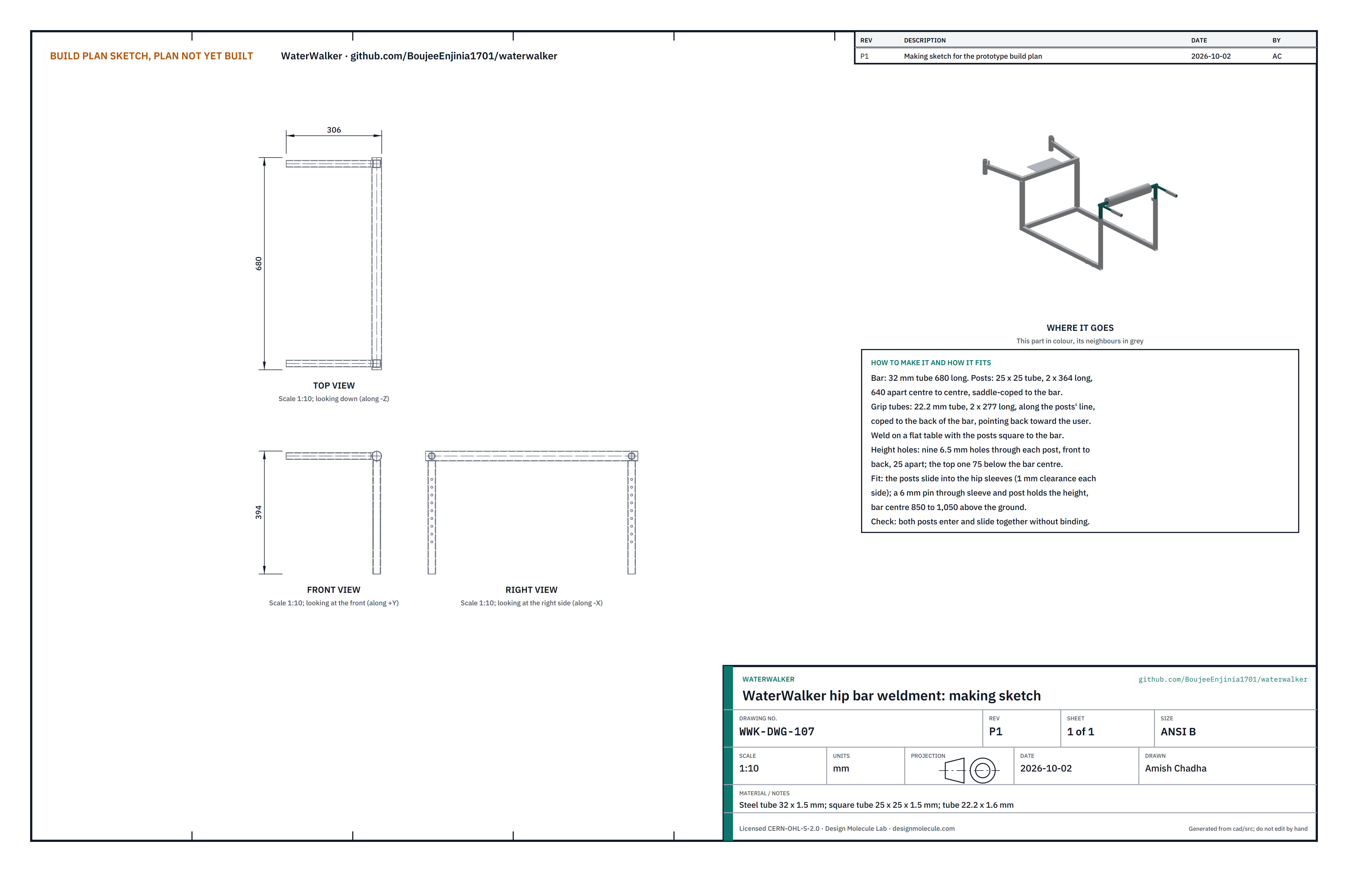
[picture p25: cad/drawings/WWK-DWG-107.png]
Figure 16. Making sketch of the hip bar weldment


*Figure 16. Hip bar weldment making sketch (WWK-DWG-107).*

**What it is and what it is made from.** The bar the user pushes with her hips and the two grip tubes for her hands, on two posts that slide into the hip sleeves. Round tube 32 x 1.5 mm, square tube 25 x 25 x 1.5 mm and round tube 22.2 x 1.6 mm.

**How to make it.**

1. Cut the bar 680 long, the two posts 364 long and the two grip tubes 277 long.
2. Saddle-cope the top of each post to the bar. Weld the posts under the bar, 640 apart centre to centre, square to it, on a flat table.
3. Cope one end of each grip tube to the back of the bar and weld it level, in line with its post, pointing back toward the user.
4. Drill nine 6.5 holes front to back through each post, 25 apart, the top one 75 below the bar centre.

**How it fits the parts next to it.**

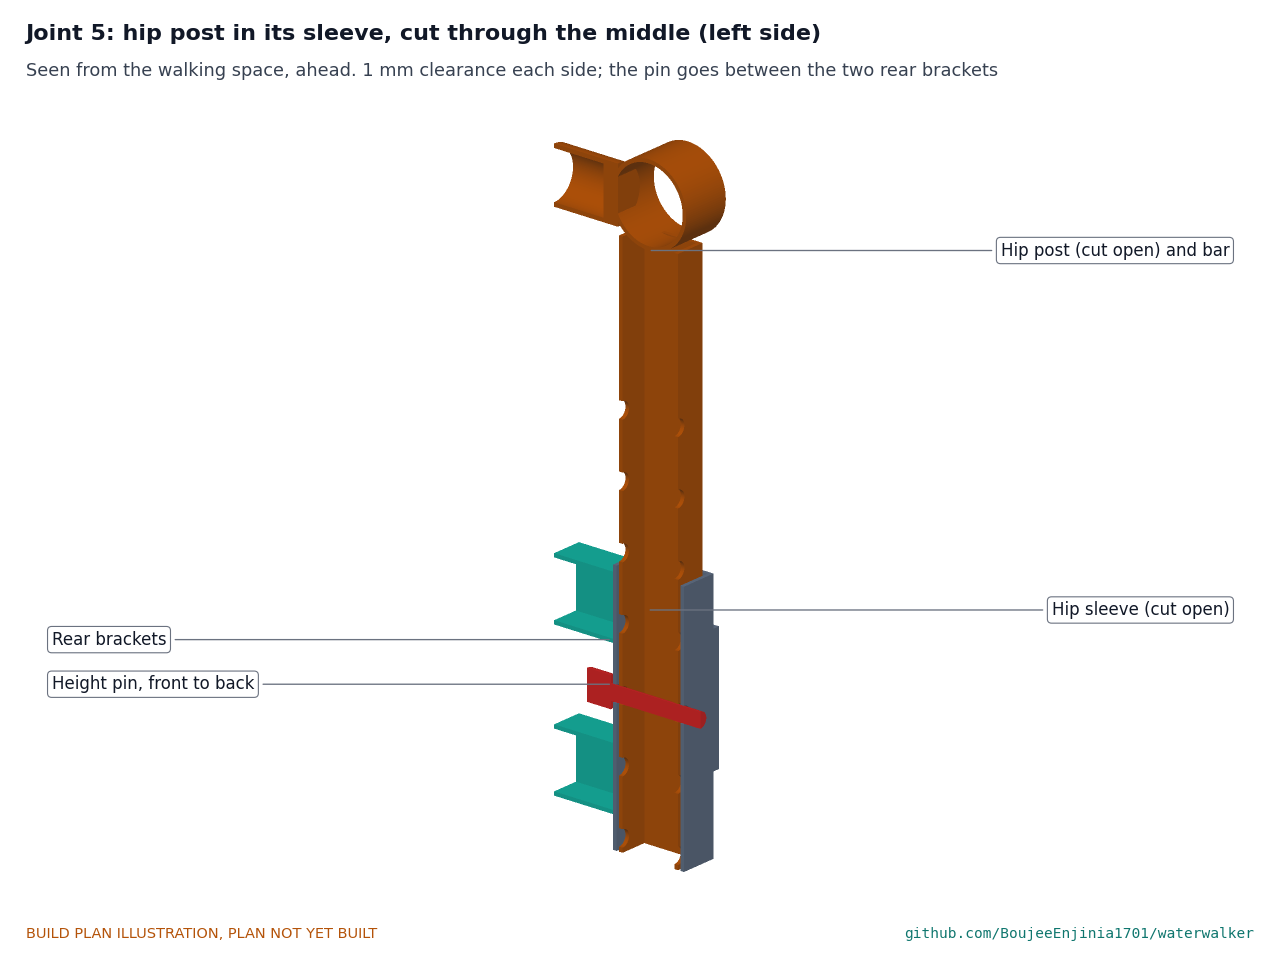
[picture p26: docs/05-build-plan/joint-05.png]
Figure 17. Joint 5: hip post in its sleeve


*Figure 17. Joint 5. Each post slides in its sleeve with about 1 mm clearance each side; a 6 mm pin through sleeve and post sets the height, passing between the two rear brackets.*

The pad slides over the bar; a bicycle grip goes on the rear end of each grip tube, with the brake lever ahead of the right grip and the bail lever ahead of the left grip. The nine holes give a bar height of 850 to 1,050 above the ground in 25 steps; at 1,050, 150 of the post stays in the sleeve.

**Check before moving on.** Both posts enter both sleeves together and slide without binding at every height.

### 3.8 Cradle

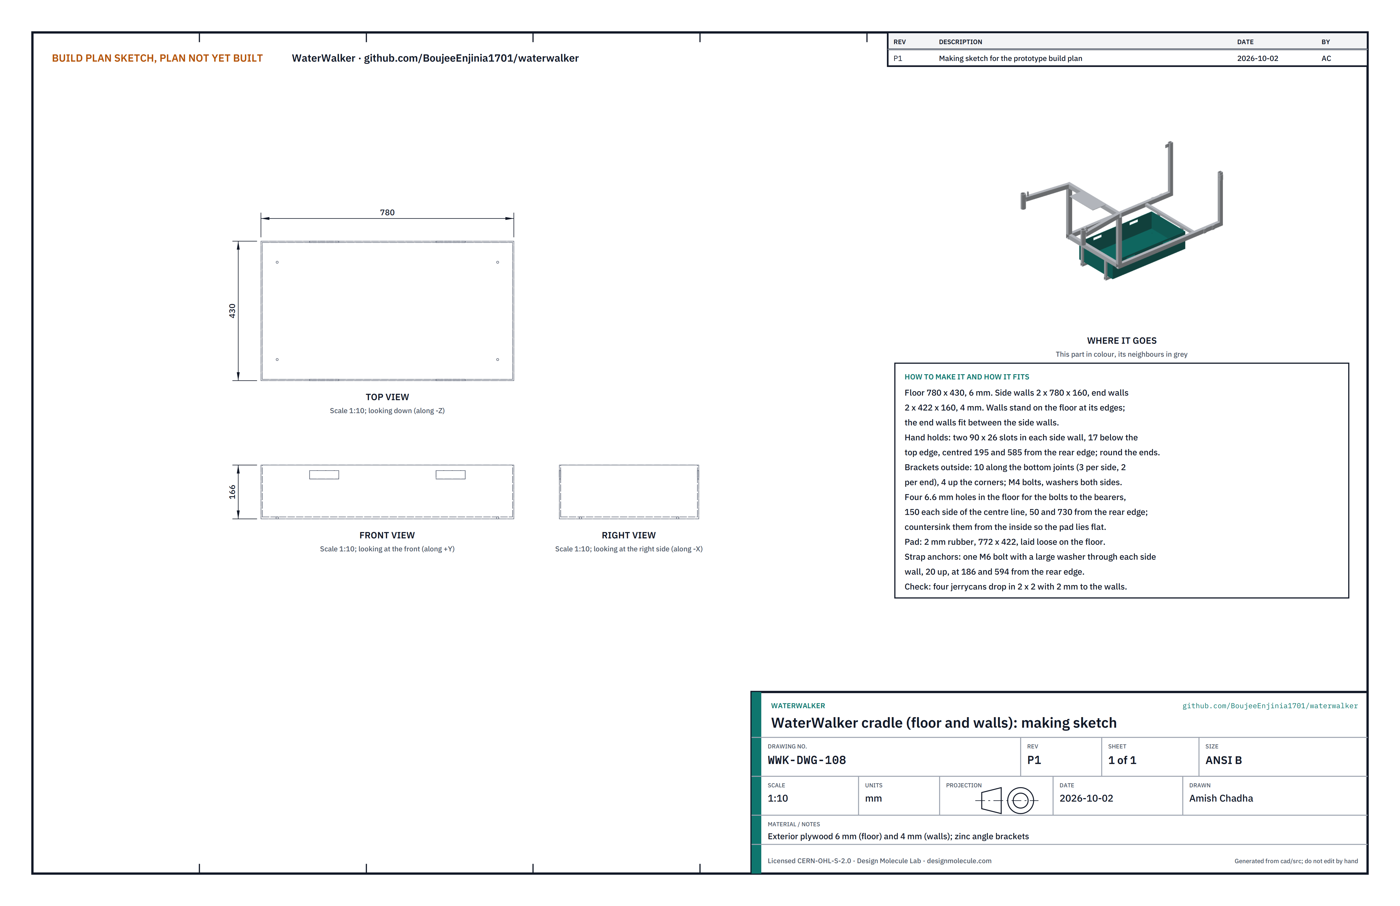
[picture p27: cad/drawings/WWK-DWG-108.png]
Figure 18. Making sketch of the cradle


*Figure 18. Cradle making sketch (WWK-DWG-108).*

**What it is and what it is made from.** A low plywood tray that the four jerrycans stand in, with a rubber pad on its floor. Exterior plywood 6 mm (floor) and 4 mm (walls), 14 zinc angle brackets, rubber cut from used inner tubes or tires.

**How to make it.**

1. Cut the floor 780 x 430 (6 mm), two side walls 780 x 160 and two end walls 422 x 160 (4 mm).
2. Seal every edge with exterior paint or varnish and let it dry (seal the hand hold edges after step 6).
3. Stand the side walls on the floor's long edges, flush outside; fit the end walls between them, on the floor's short edges.
4. Hold the joints with angle brackets outside: three along each side wall's bottom, two along each end wall's bottom, one up each corner. Drill through bracket and plywood and fit M4 bolts with washers both sides.
5. Drill four 6.6 holes in the floor for the bearer bolts, 150 each side of the centre line, 50 and 730 from the rear edge; countersink them from the inside.
6. Cut two hand holds in each side wall: slots 90 long and 26 high, their top edge 17 below the wall top, centred 195 and 585 from the rear edge. Drill the slot ends and saw between, then round and seal the cut edges.
7. Fit the two strap anchors: an M6 bolt with a large washer through each side wall, 20 above the floor, at 186 and 594 from the rear edge, with a webbing loop under its head.
8. Cut the pad 772 x 422 and lay it loose on the floor.

**How it fits the parts next to it.**

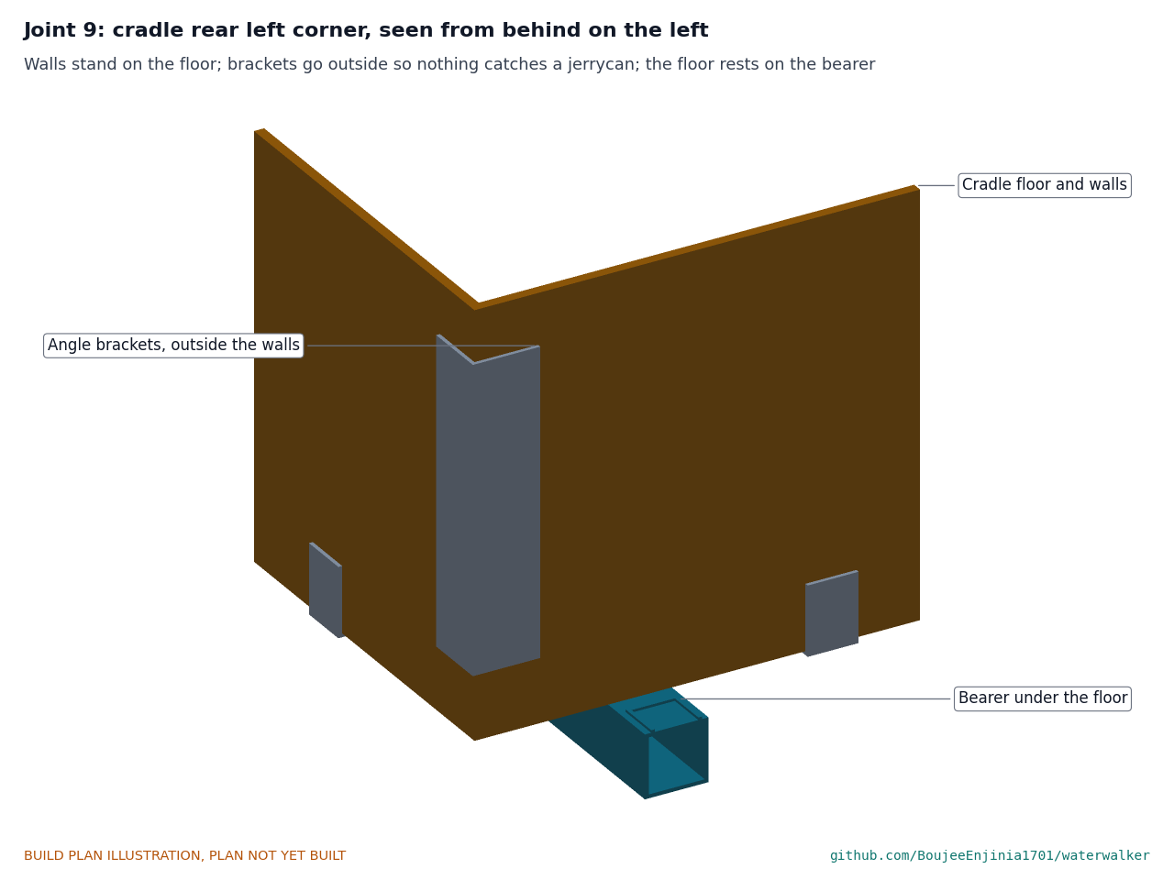
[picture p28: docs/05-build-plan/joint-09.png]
Figure 19. Joint 9: cradle corner


*Figure 19. Joint 9. The walls stand on the floor; brackets go outside so nothing catches a jerrycan; the floor rests on the bearer (the bolt is shown in Figure 8).*

Four M6 countersunk bolts go down through the floor and the bearers, with nyloc nuts underneath. The jerrycans stand 2 x 2 on the pad with 2 mm to each wall.

**Check before moving on.** The tray is square within 3 mm on its diagonals, four jerrycans drop in and lift out by hand, and the empty tray lifts out by its hand holds.

### 3.9 Hold-to-release brake: spring unit, bail and cables

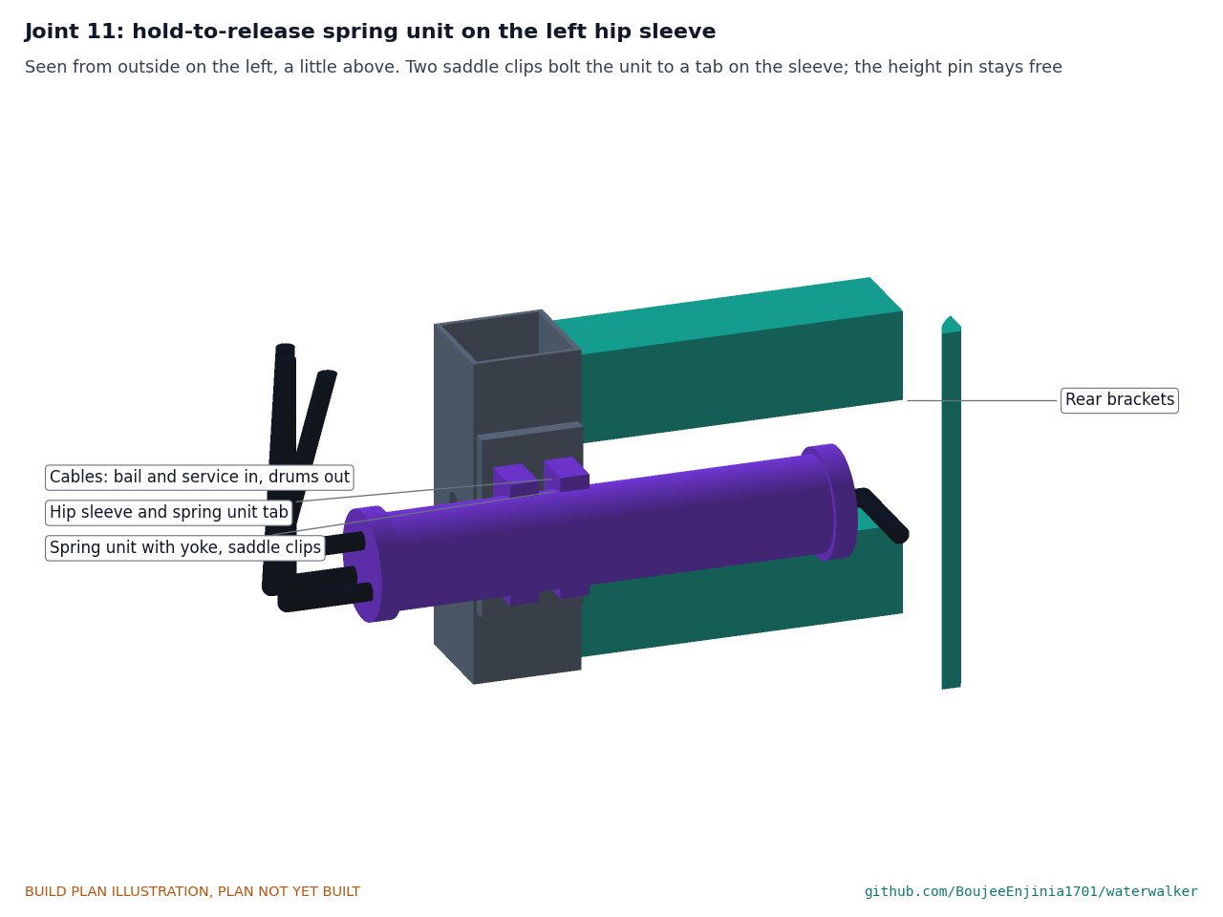
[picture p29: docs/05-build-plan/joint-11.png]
Figure 20. Joint 11: spring unit on the left hip sleeve


*Figure 20. Joint 11. The spring unit lies along the outside of the left hip sleeve, bolted by two saddle clips to the tab on the sleeve, between the two rear brackets' levels and clear of the height pin.*

**What it is and what it is made from.** A brake that comes on by itself if the user lets go. A spring in a short steel tube pulls both rear drum cables through a cable yoke; the user holds it off by holding a bail lever up against the left grip. The service lever on the right grip pulls the same yoke, so either one brakes both rear wheels. Steel tube 26 mm outside, 132 long, with two welded end caps; a compression spring of about 390 N preload and 10 N/mm; a toggle; a bought cable yoke that lets either input cable pull both output cables; two saddle clips with M5 bolts; a bought bail lever for 22.2 mm tube with a 120 mm blade.

**How to make it.**

1. Cut the tube 132 long and deburr it. Drill the front end cap for three cable housings (the bail and service cables in, the right drum cable out) and the rear end cap for one (the left drum cable out).
2. Fit the yoke, the toggle and the spring inside, following the yoke maker's drawing, with the spring pushing the yoke toward the rear so that it pulls both drum cables.
3. Weld the front end cap on; the rear end cap screws on so the spring can be reached.
4. Bolt the unit to the tab on the left sleeve with the two saddle clips.

**How it fits the parts next to it.** The unit's inner side sits on the 4 mm tab, so the height pin through the sleeve stays free. The bail cable runs from the bail along the outside of the left grip tube and down in front of the left post to the unit's front end. The service cable runs from the right lever under the right end of the hip bar and along the front of the pad to the unit. The right drum cable goes back along the front of the pad, down the outside of the right sleeve, in front of and outside the right rear head tube, in front of the fork crown and down the front of the outer blade to the drum; the left drum cable leaves the rear of the unit and does the same on the left. Every housing is tied to the tube it runs along, with a loop at each sleeve so the hip bar can be raised to its top hole. Nothing crosses the open rear, and no cable stands out past the axle nuts.

**Check before moving on.** With the bail let go, both drums are on and the wheels will not turn by hand; squeezing the bail fully home releases both; with the bail held, the service lever still brakes both drums.

### 3.10 Bought components

Buy to specification, not brand. Line numbers are those of the bill of materials.

- **Rear wheels (line 2).** 26 in (559 mm bead seat) alloy rims, 36 spokes, 100 mm front-type drum-brake hubs (70 mm drum) with their reaction arm and clip. **Front wheels (line 3).** The same rims on 100 mm plain hubs.
- **Forks (lines 2 and 5).** Four rigid 26 in steel forks, 1 1/8 in steerer at least 170 mm above the crown, 100 mm dropouts, offset as near 60 mm as the market offers. All four are the same.
- **Headset and lock sets (line 16).** Four 1 1/8 in external-cup headsets for a 34 mm bore, with top caps and star nuts; four 40 mm clamp collars for 28.6 mm (made into lock collars, section 3.4); four 8 mm steel pins 75 to 90 long with a ring and an R-clip.
- **Tires (line 14).** Four 26 x 2.1 to 2.4 in puncture-resistant tires, thorn-resistant tubes and liners.
- **Brakes (line 7).** One brake lever with a parking latch for 22.2 mm bars, with its cable and housing.
- **Hold-to-release brake (line 17).** A bail lever for 22.2 mm bars with a long blade; a compression spring of about 390 N preload and about 10 N/mm; a cable yoke for two inputs and two outputs; three brake cables and housing.
- **Hip bar parts (line 4).** A foam pad for a 32 mm bar, 480 long; two bicycle grips; two 6 mm pins with a ring and R-clip.
- **Parking lock pin (line 15).** A 10 mm ball-lock pin with about 140 mm usable length, a pull ring and a lanyard.
- **Skirt guard clips (line 8).** Four rubber-lined steel clips for the fork blade, with 5 mm spacers and M6 bolts.
- **Fixings and finishes (line 12).** M6, M5 and M4 bolts with nyloc nuts and washers, axle nuts, plastic tube end caps, primer and paint, red rear and white front reflectors, cable ties, two rated load and slope plates (150 x 30, engraved or printed with the rated load of 90 kg gross in the cradle and the steepest rated slope).

## 4. Putting it together

In each picture the parts already fitted are grey and the part being fitted is in colour, with an arrow showing the way it goes in. Paint the frame, the brackets and the carrier before step 1, and let the paint harden.

### Step 1: headset cups into the four head tubes

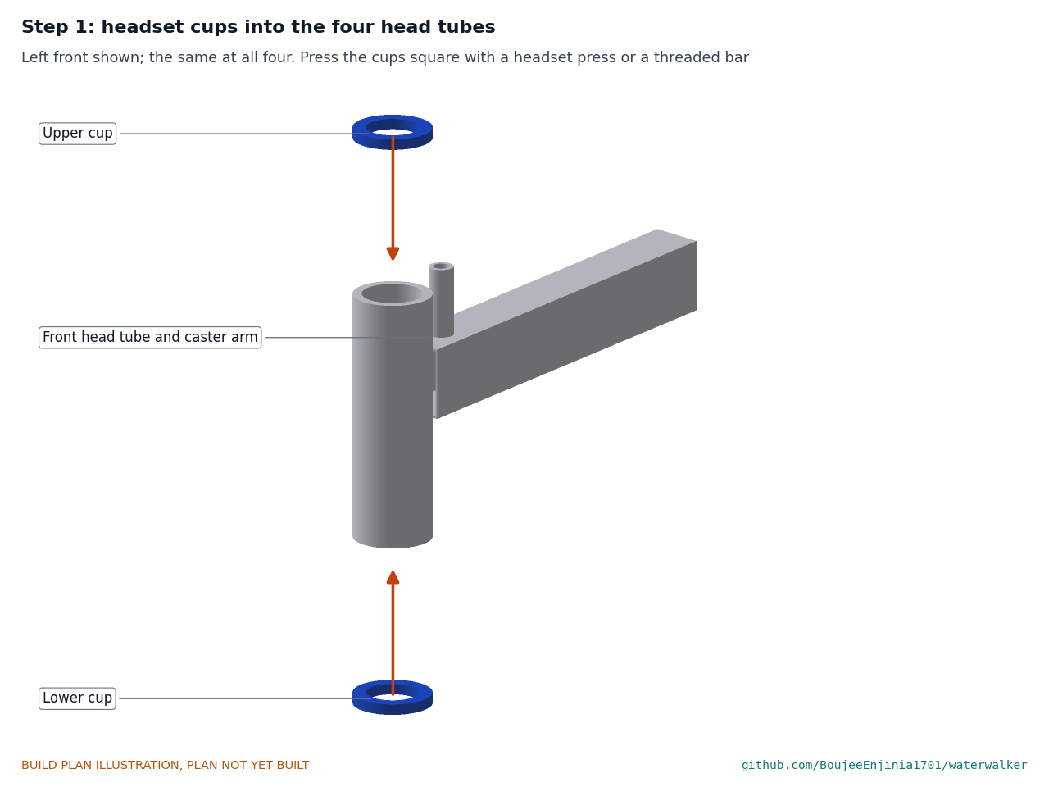
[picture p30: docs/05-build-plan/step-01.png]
Step 1


Press the lower and upper cups square into each head tube with a headset press or a threaded bar and two thick washers. The same at all four corners.

### Step 2: rear forks into the rear head tubes

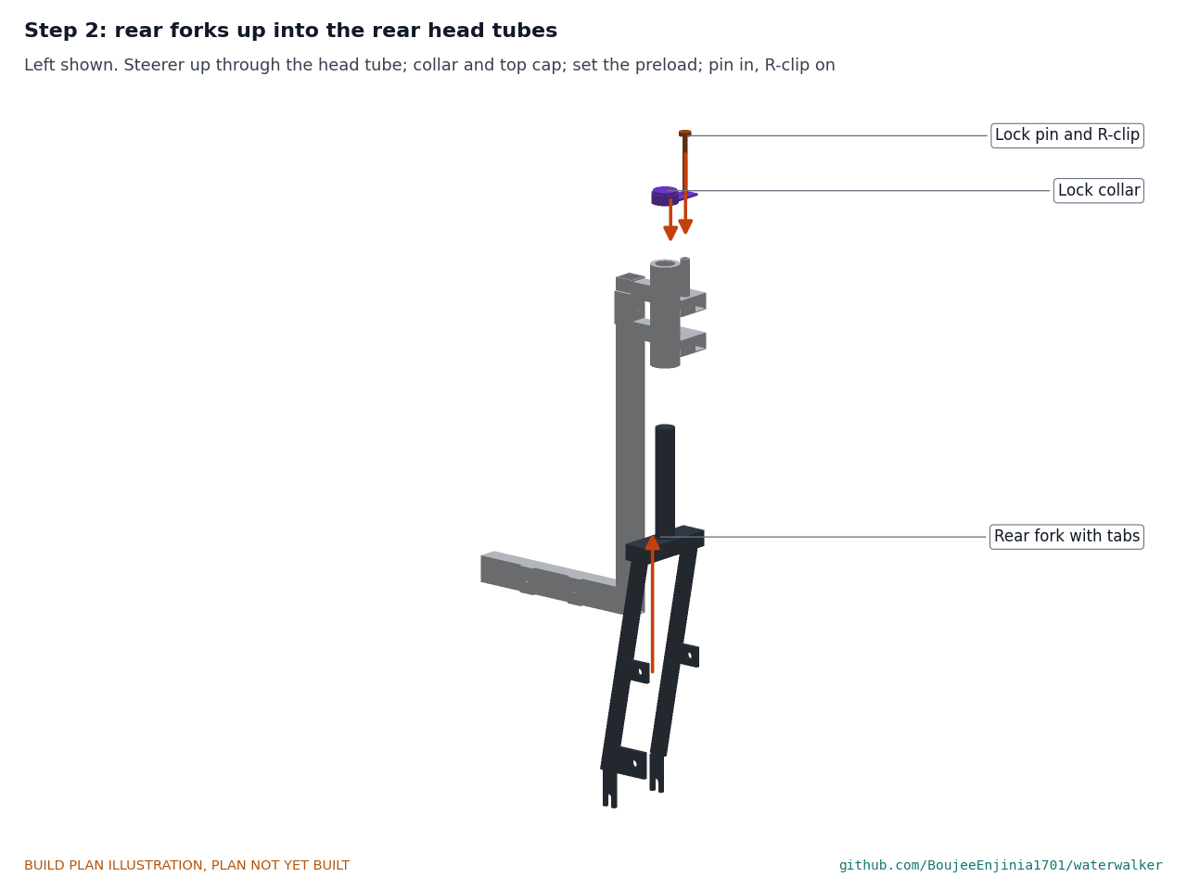
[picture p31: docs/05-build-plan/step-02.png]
Step 2


Fit the crown race, grease the bearings and push each rear fork's steerer up through its head tube, with the dropouts ahead of the steering axis. Slide on a 2 mm spacer and the lock collar, fit the star nut and top cap, and tighten the top cap until the fork turns without play. Turn the fork straight, tighten the collar bolt with its hole over the pin guide, and drop in the lock pin with its R-clip. **Hold point:** each rear fork is straight (sight the dropouts against the front head tube) and cannot turn.

### Step 3: front forks into the front head tubes

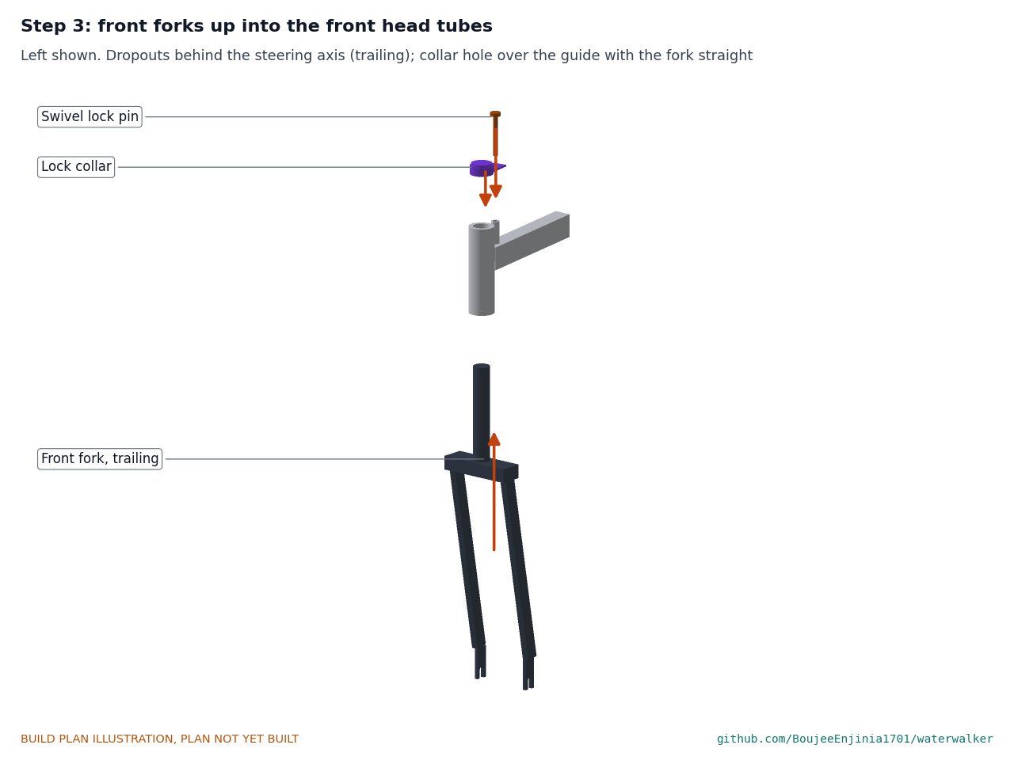
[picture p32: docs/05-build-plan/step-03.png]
Step 3


As step 2, but with the dropouts behind the steering axis so the wheel trails. Tighten the collar with its hole over the guide when the fork points straight back. The swivel lock pin drops in to lock the caster straight and lifts out to let it swivel.

### Step 4: skirt guards

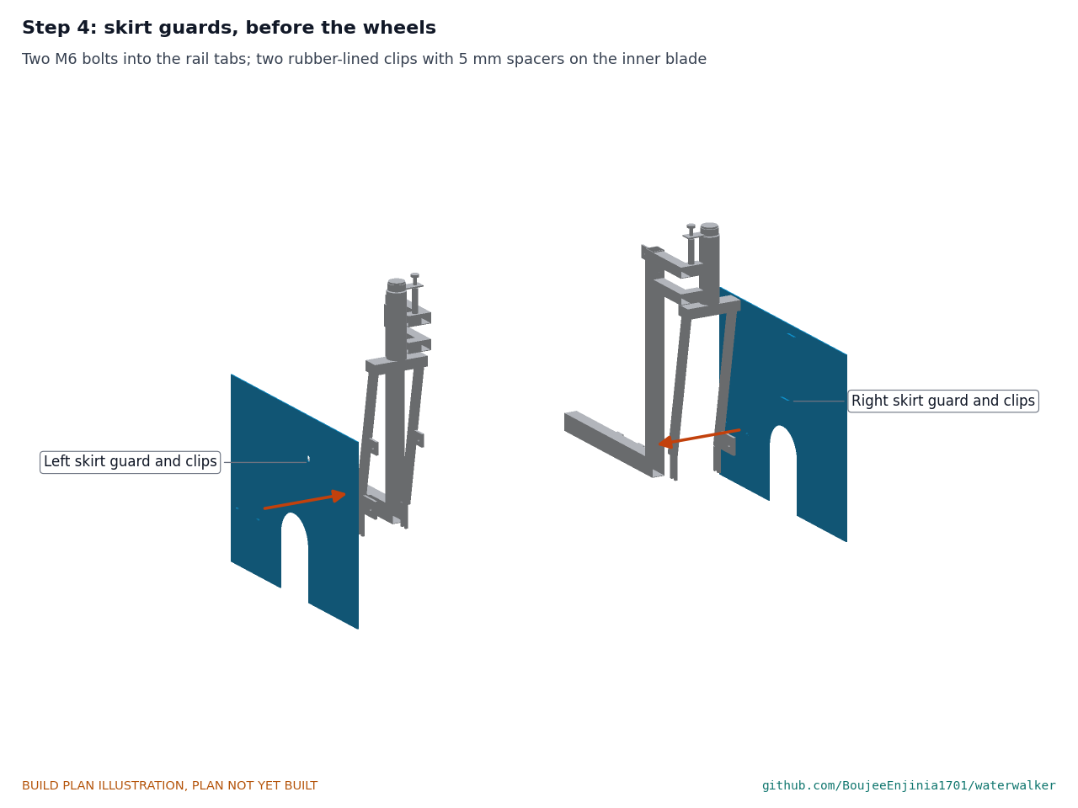
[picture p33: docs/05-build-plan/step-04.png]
Step 4


Before the wheels. Hold each guard flat against its two rail tabs, fit two M6 bolts with washers, then fit the two clips round the inner fork blade with their spacers and M6 bolts through the guard.

### Step 5: rear wheels

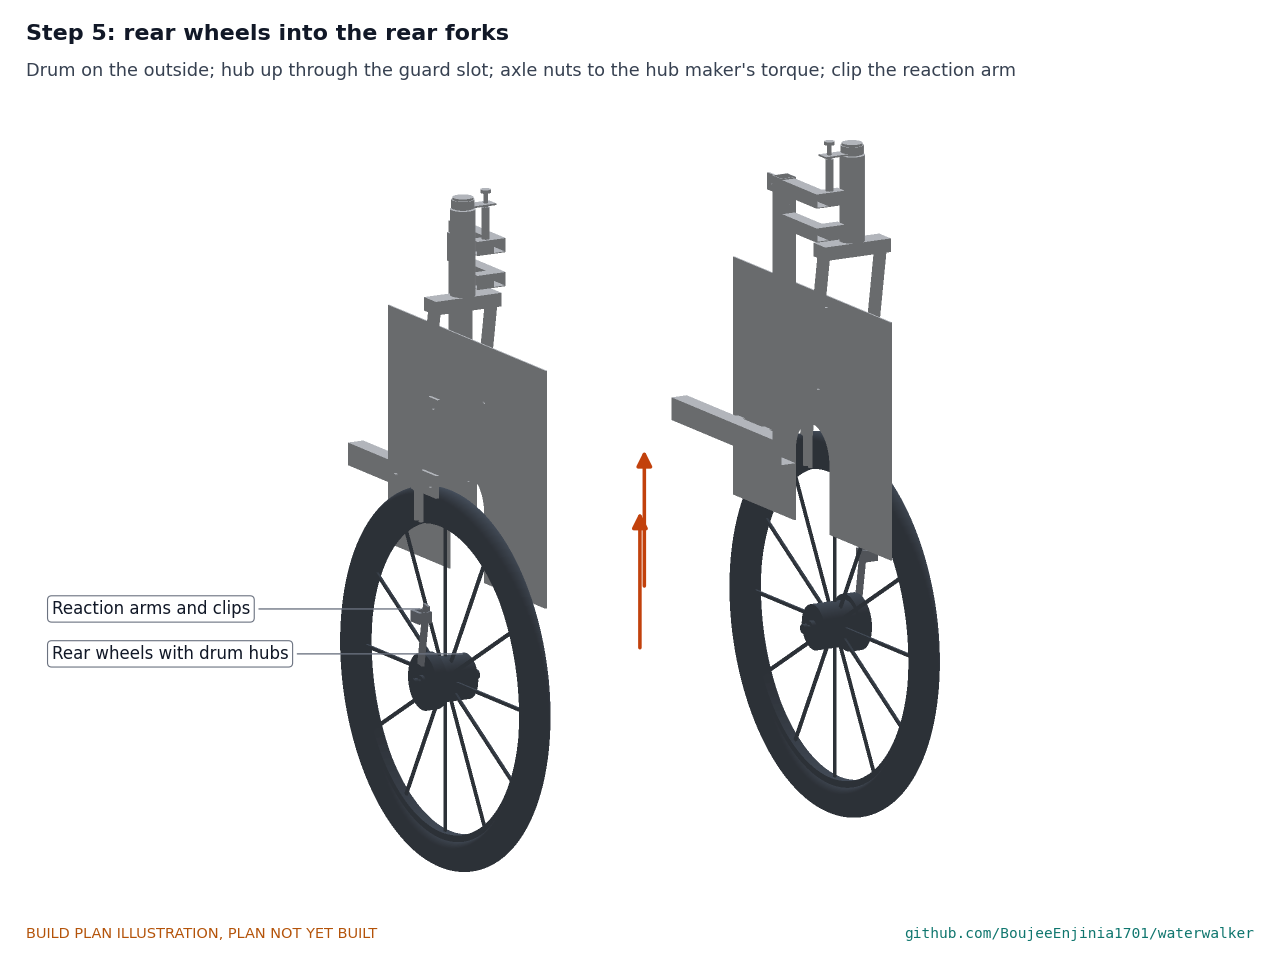
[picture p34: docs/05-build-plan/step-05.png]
Step 5


Fit the tire, liner and tube to each wheel first. Lift each rear wheel into its fork with the drum on the outside, the hub rising into the guard's slot. Fit the axle nuts to the hub maker's torque, lay the reaction arm along the outer blade and fit its clip. Spin each wheel: nothing touches.

### Step 6: front wheels

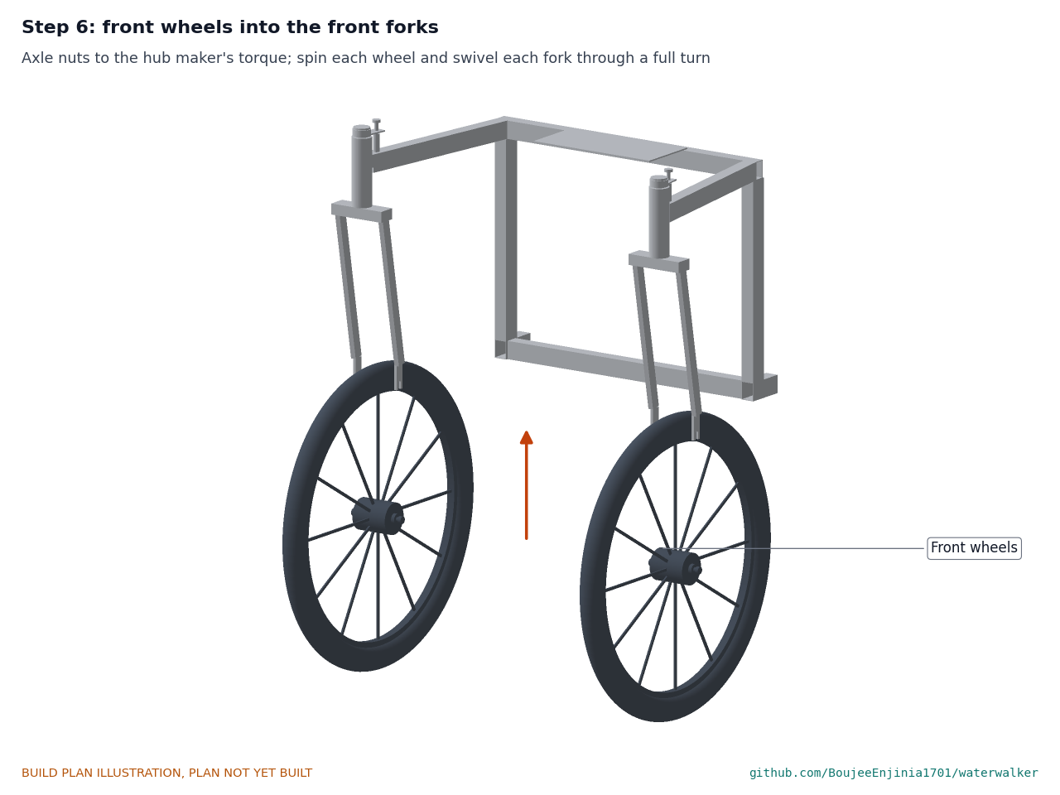
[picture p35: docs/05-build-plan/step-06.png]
Step 6


Fit tires as in step 5, then the front wheels, axle nuts to the hub maker's torque. With the lock pins out, swivel each fork through a full turn: the tire clears the riser and rail by about 20 mm.

### Step 7: hip bar

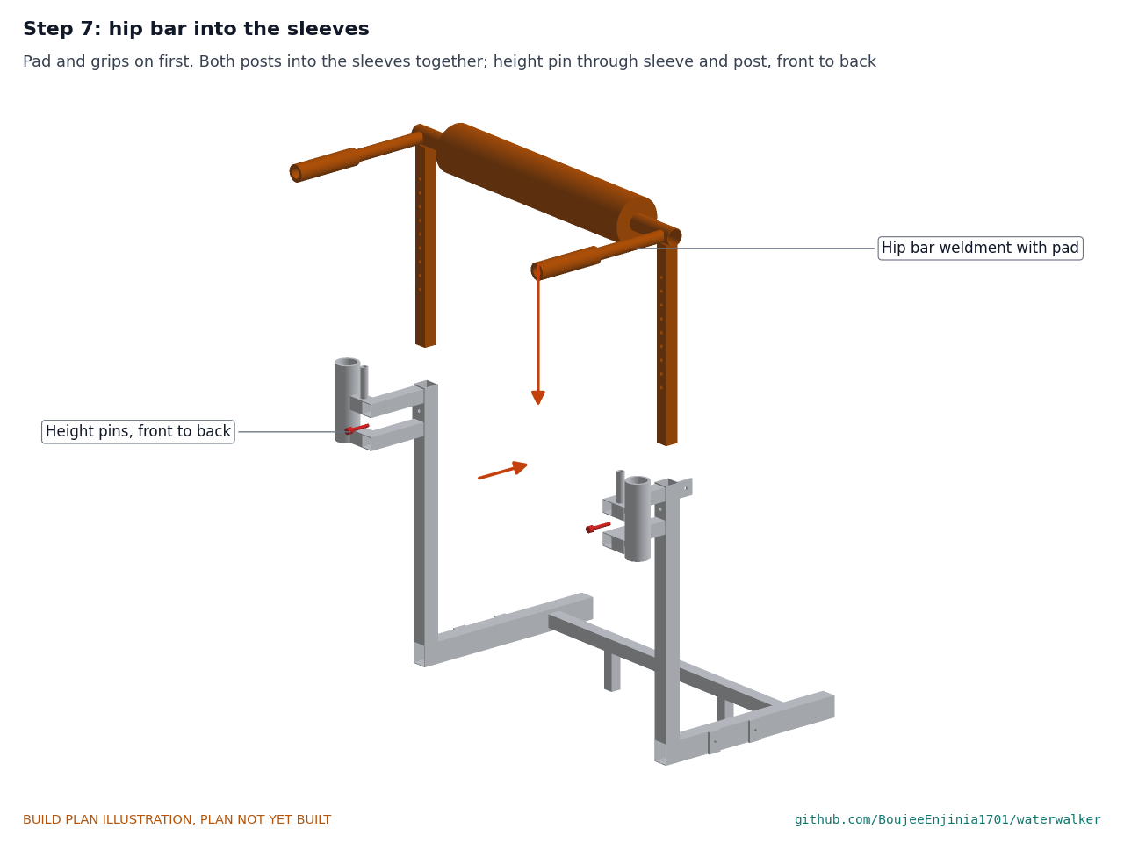
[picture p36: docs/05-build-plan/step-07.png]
Step 7


Slide the pad onto the bar and the grips onto the grip tubes (both grips after step 8). Lower both posts into the sleeves together and fit the height pins front to back at the user's height.

### Step 8: brake lever, bail lever and grips

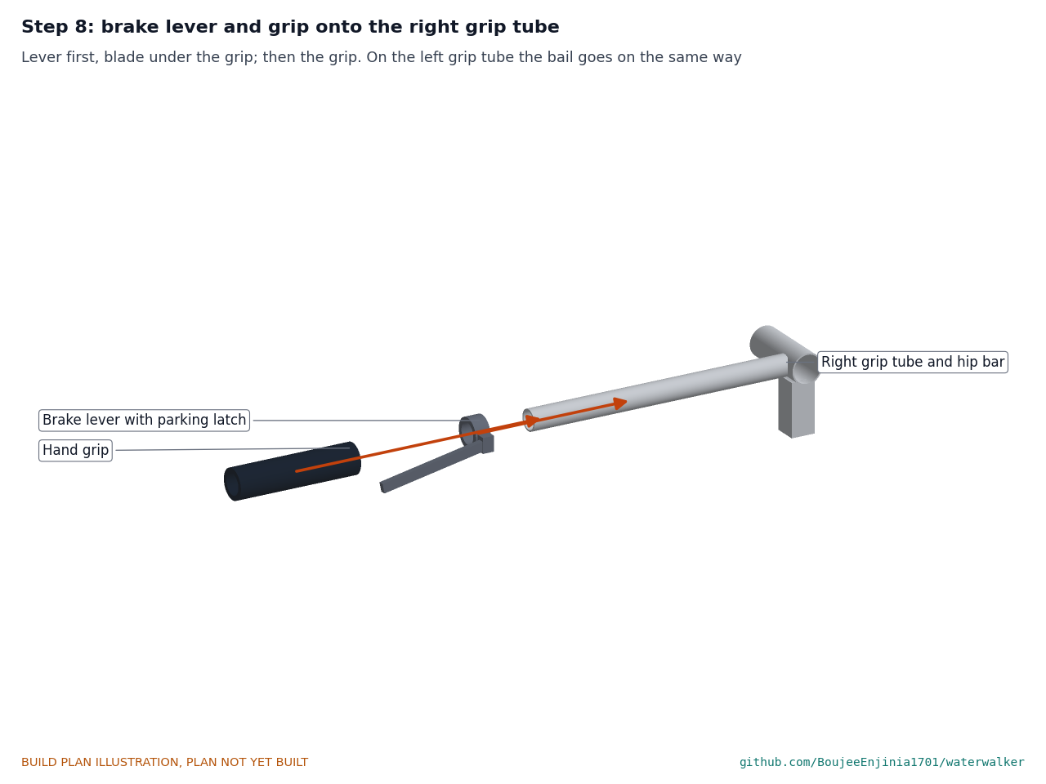
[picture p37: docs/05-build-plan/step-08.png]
Step 8


Slide the brake lever onto the right grip tube ahead of where the grip goes, then the grip. Do the same on the left with the bail lever, its blade under where the grip goes, then the left grip.

### Step 9: hold-to-release brake: spring unit and cables

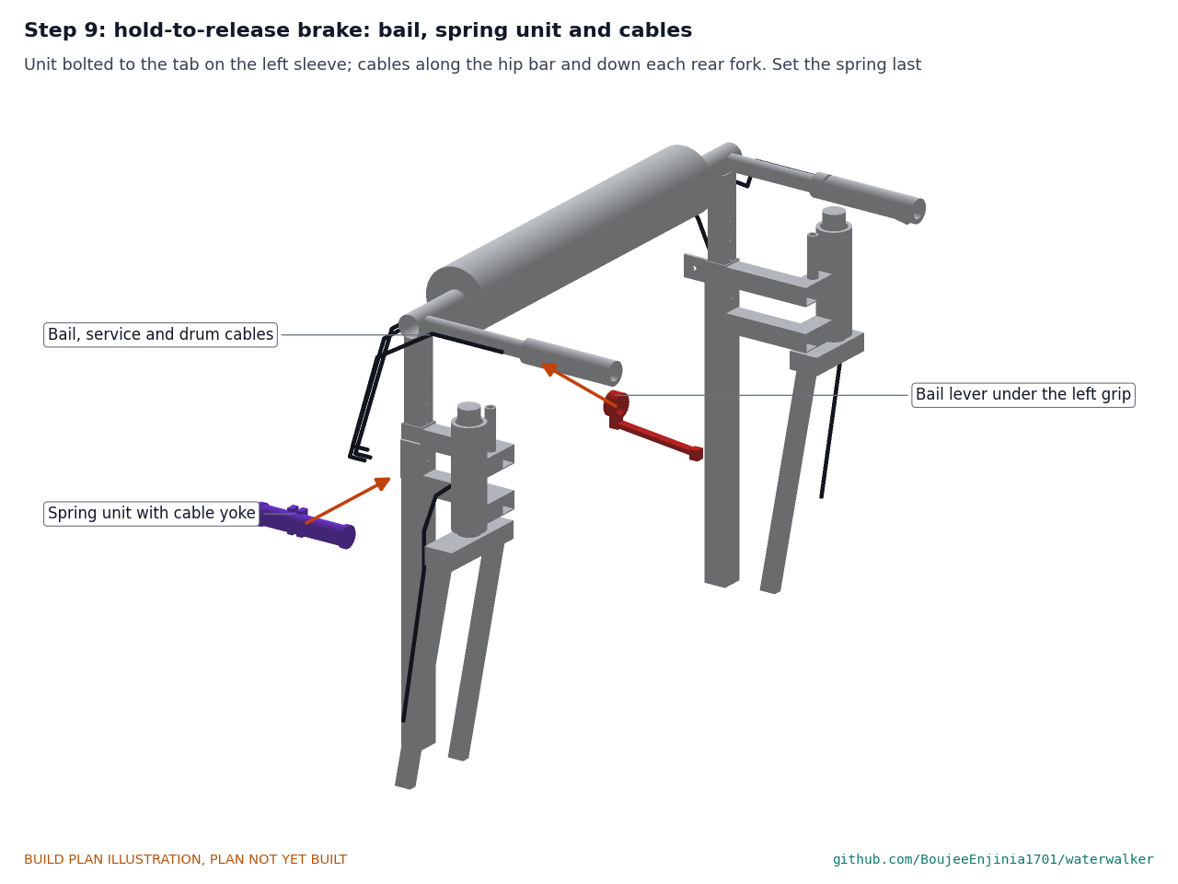
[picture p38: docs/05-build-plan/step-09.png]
Step 9


Bolt the spring unit to the tab on the left sleeve with its two saddle clips. Run the cables as described in section 3.9 and tie them to the tubes. Connect the two drum cables to the drums with the spring backed off, then set the spring last. Adjust both drums to bite at the same travel, from the service lever and from the bail. **Hold point:** with the bail let go the wheels cannot be turned by hand; with it squeezed home they turn freely.

### Step 10: cradle

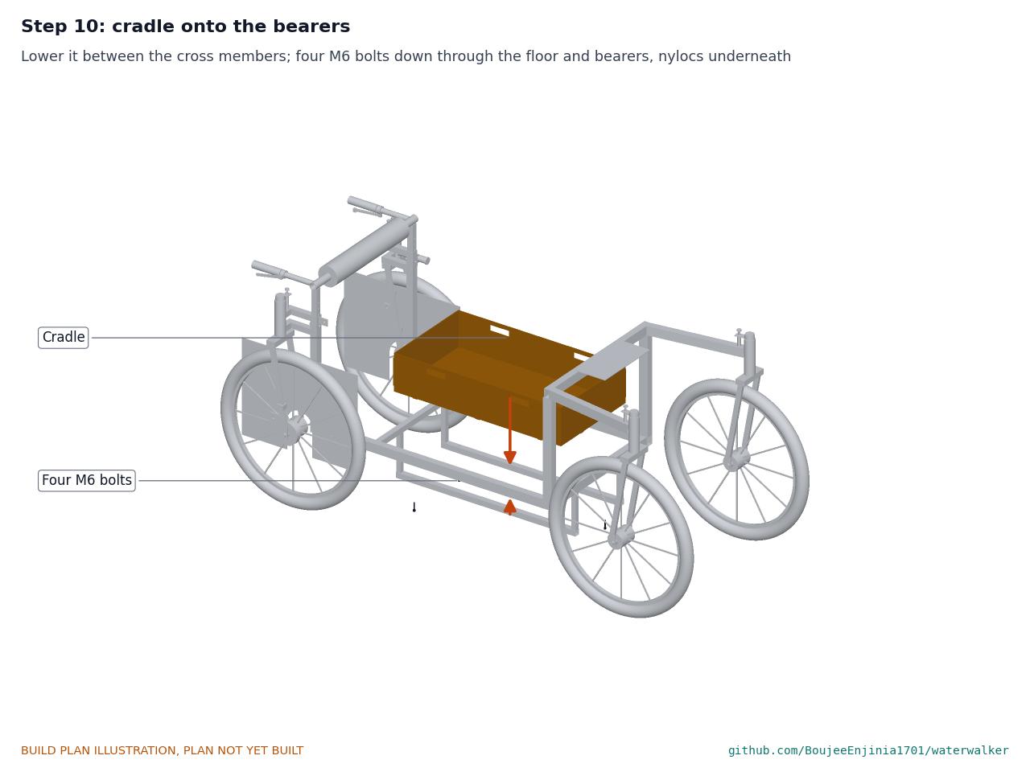
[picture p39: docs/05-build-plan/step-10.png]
Step 10


Lower the cradle between the cross members onto the bearers and fit four M6 countersunk bolts down through the floor and bearers with nyloc nuts underneath.

### Step 11: parking lock pin

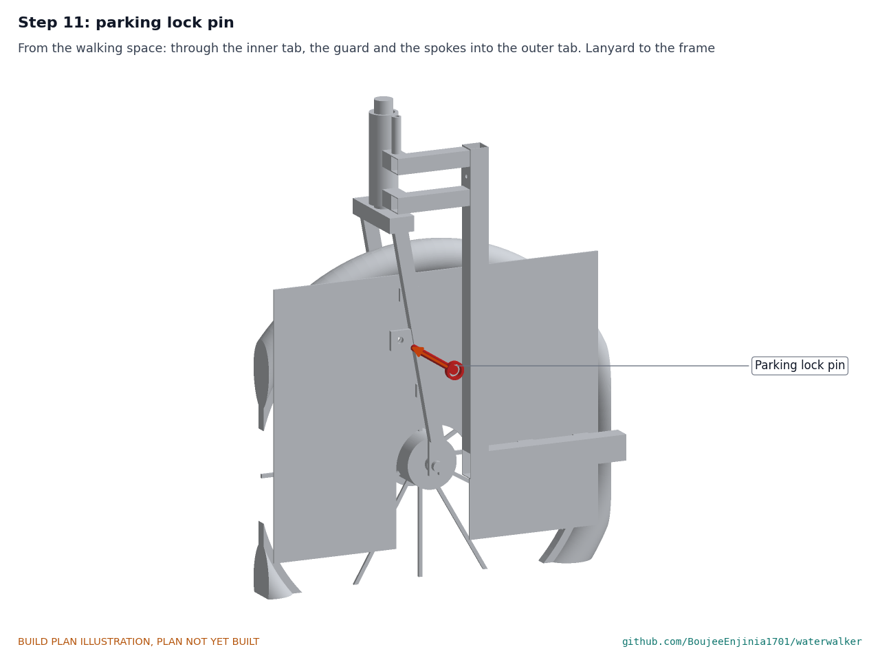
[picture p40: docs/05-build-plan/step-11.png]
Step 11


Tie the lanyard to the left sleeve. From the walking space, push the pin through the inner tab, the guard and between the spokes into the outer tab; roll the wheel a little if a spoke is in the way. It ends inside the axle nut.

### Step 12: first load

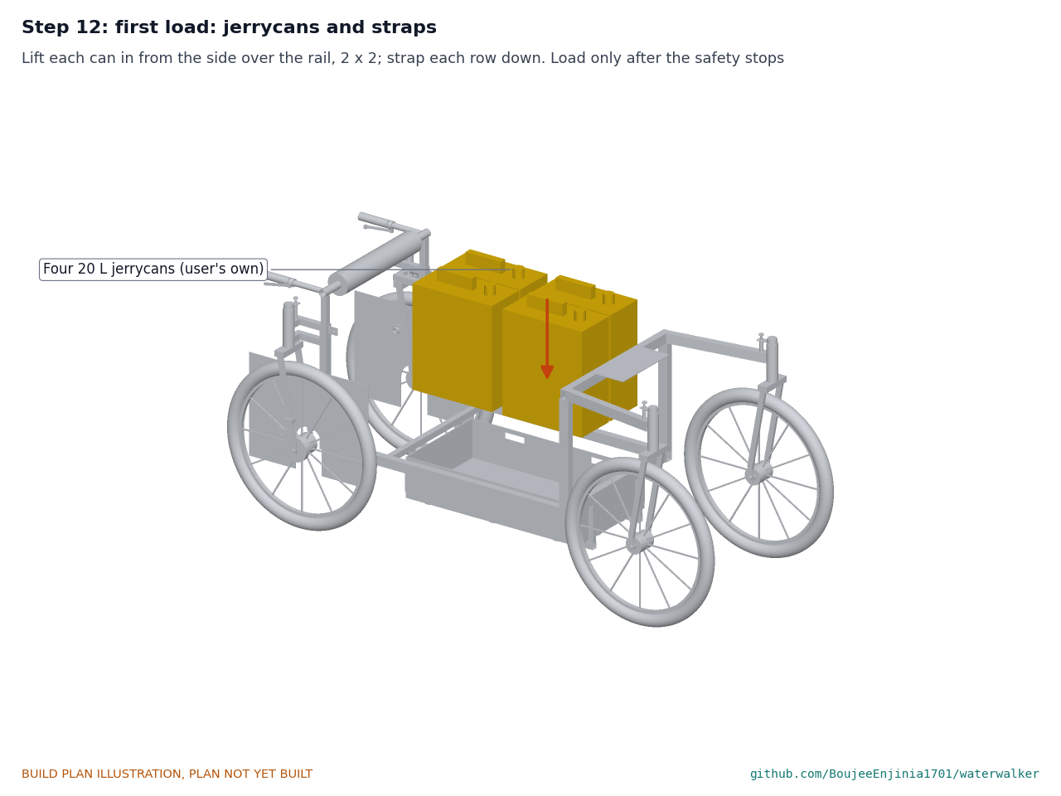
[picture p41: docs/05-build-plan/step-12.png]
Step 12


Only after safety stops S1 to S4 (section 6). Lift each jerrycan in from the side over the rail and stand them 2 x 2; strap each row down to the strap anchors.

## 5. First checks

These are the checks a TRL 4 test report would record; this plan only lists them. Requirement numbers are those of WWK-REQ-001.

*Table 3. First checks.*

| Check | Requirement | How | Pass when |
| --- | --- | --- | --- |
| Width | R6 | Tape over the axle nuts and the lock pin | 900 mm or less (898 mm by design) |
| Walk-in fit | R7 | Measure between the rails; a user walks in and sets the hip bar at 850, 950 and 1,050 | 600 mm or more clear; no step-over; the pin fits at each height |
| Caster swivel and sweep | R5 | Swivel each front fork through a full turn; lock it straight with the pin | No contact; about 20 mm to the riser; the pin drops in only when straight |
| Turning circle | R5 | Turn 180 degrees about the inner rear wheel on a flat yard, casters free | Within a 4.0 m circle without lifting a wheel |
| Lift height | R8 | Measure the rail top and lift a full jerrycan in from each side | 450 mm or less (364 mm by design) |
| Brakes | R10, R4 | Lever pull on a 10 % ramp, loaded; push the lever latch on | Both drums lock at the same travel; the latch holds the lever |
| Hold-to-release brake | R10, R4 | On a 10 % ramp, loaded, walking slowly downhill, let go of the bail with a second person ready; measure the squeeze and hold forces at the bail | The carrier stops and stays stopped; it stops within about 3 m from walking pace; squeeze and hold forces recorded (about 98 N and 24 N by estimate) |
| Parking lock | R10 | Loaded on a 20 % ramp, latch off, lock pin in, facing downhill and uphill | The carrier does not move; the pin comes out by hand afterwards |
| Push force | R2, R3, R4 | Force gauge at the hip bar, loaded, on firm level dirt, loose sand and a 10 % climb | Recorded against 60, 150 and 180 N |
| Empty mass | R9 | Weigh the empty carrier | Recorded against 35 kg (40.3 kg estimated) |
| Frame after first load | R1 | Load 90 kg in the cradle for 10 minutes; check every weld and the bearers | No crack, no lasting bend; bearers level within 2 mm |
| Weld inspection at every service | R1 | Clean and look at the rear cross member welds and both caster arm welds under a bright lamp, with a magnifier; dye penetrant if available | No crack; any crack stops use until the joint is repaired. Repeat at every service until the fatigue test at TRL 4 shows the joints need no gussets |

## 6. Safety stops

Stop at each point. Carry on only when everything listed is true.

- **S1. Before any load goes in the cradle.** Every weld inspected under a bright lamp, with no cracks or undercut at the caster arms, risers, rear brackets, hangers and the fork tabs. All four axle nuts at the hub maker's torque. Both rear forks pinned straight.
- **S2. Before the carrier leaves the bench.** Both drums brake at the same lever travel and the latch holds. The lock pin goes in and out by hand. No sharp edge or tube end is open; every end cap fitted.
- **S3. Before the first loaded push.** A flat, level yard with no road traffic and nobody in the swivel zone of the front wheels. Start with two jerrycans, then four. The user knows how to set the latch and the lock pin.
- **S4. Before any slope.** The parking test of section 5 passed on the ramp. The hold-to-release brake tested before the first loaded descent: on the 10 % ramp with two jerrycans and then four, the user lets go of the bail and the carrier stops and stays stopped, both drums biting. A second person stands downhill. Casters pinned straight on descents and cross-slopes.
- **S5. Before anyone else uses it.** The two rated load and slope plates are fitted and readable: the rated load (90 kg gross in the cradle) and the steepest rated slope.
- **S6. At every service until the TRL 4 fatigue test.** The rear cross member and caster arm welds inspected as in section 5; use stops at any crack.

## 7. Tools, skills and workspace

**Tools.** Angle grinder with cutting, grinding and flap discs, or a metal cutting saw; bench vice; drill press or a drill in a stand; drills 3 to 14 mm and a 9 mm drill; M6 tap; hole saw or file for tube coping (a tube notcher if available); arc or MIG welder suited to 1.2 mm wall tube; welding magnets and clamps; steel rule, tape, square, protractor and spirit level; headset press or threaded bar; crown race setting tool; bicycle tools (spoke key, cone spanners, 15 mm axle spanner, tire levers, pump, Allen keys); jigsaw or handsaw for plywood; utility knife for the rubber and HDPE; torque wrench covering about 5 to 40 N·m; luggage scale or platform scale; force gauge for the first checks.

**Skills.** A welder who can weld thin-wall tube without burning through and who has welded to steel bicycle forks; a bicycle mechanic for the headsets, wheels, brakes and the hold-to-release brake's cables (or the same person with both skills); basic woodwork. No electrical work is part of this build.

**Workspace.** A flat concrete floor about 3 x 2 m to build the frame on; a ventilated welding area away from anything that burns; a ramp or slope of known grade (10 % and 20 %) for the first checks.

**Personal protective equipment.** Welding helmet, leather gloves and cotton clothing when welding; safety glasses and hearing protection when grinding; gloves when handling cut tube; no gloves near a turning drill.

## 8. Where the numbers come from

- Model and constructability checks: `cad/src/model.py` (`python cad/src/model.py --check`, 104 checks); STEP and STL exports in `cad/step/` and `cad/stl/`.
- Pictures: `cad/src/build_plan_media.py`, using `.kit/build_views.py`; written to `docs/05-build-plan/` and `cad/drawings/WWK-DWG-101` to `WWK-DWG-108`.
- General arrangement: `cad/drawings/WWK-DWG-001.pdf`, Rev P4.
- Calculations: `docs/04-calcs/01-sizing.md` (WWK-CAL-001 v0.4) and `docs/04-calcs/sizing.py`; mass section 3, frame and brackets section 7, brakes and parking section 6.
- Bill of materials: `bom/bom.csv`.
- Decisions: `docs/decisions/0003-design-for-construction.md` (WWK-DDR-003), with WWK-DDR-001 and WWK-DDR-002; decisions made and items to confirm in `docs/06-design-decisions.md` (WWK-DEC-001).
- Requirements: `docs/03-requirements.md` (WWK-REQ-001 v0.7).

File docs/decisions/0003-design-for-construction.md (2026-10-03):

---
doc_id: WWK-DDR-003
title: WaterWalker design for construction
project: WaterWalker
doc_type: Design decision record
version: "0.2"
status: Draft
date: '2026-10-02'
author: Amish Chadha
license: CERN-OHL-S-2.0
revisions:
- version: "0.1"
  date: '2026-10-02'
  author: Amish Chadha
  change: Changes that make the concept physically buildable, with the reason for each; made under Amish's 2026-09-30 instruction to make the design physically buildable; open for his review
- version: "0.2"
  date: '2026-10-02'
  author: Amish Chadha
  change: Accepted by Amish on 2026-10-02, with A1 and A2 decided as option (a)
---

# 0003: Design for construction

- **Date:** 2026-10-02
- **Status:** Draft; accepted. Amish, 2026-10-02: "APPROVED: The open decisions from the last wave (TremorTrace to ZeerBox) came in after the review and aren't on the page either." This approves the recommendation written for each open decision in the design decisions register (WWK-DEC-001 v0.1): every change in Table 1 is accepted as made, and A1 and A2 in Table 3 are decided as recorded there. Nothing here changes what the carrier does, its pitch or its safety case.

## Context

On 2026-09-30 Amish asked for an illustrated build plan for every repo and wrote: "If you are realising that the design cannot be built as per concept - fix the design assumptions to match and be physically feasible as you draw the illustrations." The concept model of WWK-DDR-002 showed what WaterWalker does, with correct main dimensions and interfaces, but it was a massing model: its parts were solid blocks placed where they work, not parts that can be cut, welded, bought and bolted together.

A build123d check of the concept model (each part against its neighbours, and each frame member against the cradle, the jerrycans and the rear forks) found the problems P1 to P16 below. Every one is fixed in `cad/src/model.py`, which now models each component as it is made or bought (`build_components()`) and runs 79 constructability checks (`python cad/src/model.py --check`): parts that must touch do touch, parts that must not touch are apart by at least the stated clearance, nothing overlaps, and the swept front tires stay clear of the risers. All 79 pass.

The changes keep what the carrier does: the same wheels, track, wheelbase, caster trail, hip bar height range, cradle size and height, lift height, walk-in rear, drum brakes, parking lock pin and assist mounting points.

## Decision

*Table 1. Changes made to the model, the BOM and the calculations.*

| # | Problem in the concept (build123d check) | Change made | Why this way |
| --- | --- | --- | --- |
| P1 | The side rails ran back to 15 mm behind the rear axle, through the inner blade and dropout of each rear fork (6,333 mm³ overlap per side), and carried two dropout tabs left over from the TRL 2 stub axles. | The rails end flush with the rear face of the hip sleeve, 45 mm ahead of the rear axle line. The dropout tabs are removed. | Since WWK-DDR-002 the fork holds the wheel on both sides; the rail has no job behind the sleeve, and stopping there keeps the walk-in rear open. |
| P2 | Each rear head tube hung on one 25 mm bracket, which ran into the head tube and the steerer (7,378 mm³). Parking on 20 % with the lock pin through one wheel puts about 195 N·m into that one bracket (about 190 MPa). | Two brackets, centred 745 and 805 mm above the ground, each an arm along the rail line from the sleeve's rear face and a short stub coped to the head tube (WWK-DWG-102). | The two brackets turn the parking moment into push and pull 60 mm apart: 95 MPa in the stubs, factor 2.5 on yield (WWK-CAL-001 v0.3). |
| P3 | The rear axle sat directly under the rear head tube, which needs a fork with no offset; rigid bicycle forks have an offset. | The rear head tube stands 60 mm behind the rear axle, the same offset as the front forks, so all four forks are the same part. | One fork part for all four corners; the axle position, wheelbase and track are unchanged. |
| P4 | The cradle had nothing under it. The four hangers stood on the plywood floor inside the cradle and cut through its end walls (about 13,000 mm³ each); the front pair ended 5 mm short of any frame member. | A cradle carrier: two 25 x 25 x 1.5 mm bearers under the floor, 300 mm apart, hung by four 20 x 20 x 1.5 mm hangers from the rear and front lower cross members, outside the cradle (WWK-DWG-103). The cradle bolts to the bearers with four M6 bolts. | The floor now rests on steel; the bearers are at 2.2 times yield at 2.5 g. The cradle floor stays 150 mm up, so the lift height and centre of mass are unchanged; ground clearance under the bearers is 125 mm. |
| P5 | The rear cross member, at rail height, passed through the two rear jerrycans (56,875 mm³). | It moves 17.5 mm back, to 332.5 mm ahead of the rear axle, just behind the cradle; the cans clear it by 8 mm. | Smallest move that clears the cans and still carries the rear hangers. |
| P6 | Each caster arm ran into the centre of its front head tube, through the steerer, and its root sat on a stub 65 mm outboard of the riser, so the root moment twisted the upper cross member end. | Each caster arm runs from the upper cross member's front face directly over its riser, angled 8.6 degrees outward, to the head tube, where it is coped to the tube wall. The stubs are gone; the upper cross member is one 670 mm tube on the riser tops. | The arm's bending goes straight down the riser; the head tube bore stays clear for the steerer. |
| P7 | The head tubes were solid and nothing held the forks in them; the front swivel lock pin stood in the air beside the head tube with nothing to engage. | All four head tubes are 44 mm tube with a 34 mm bore for external-cup headsets. Each steerer carries a lock collar with a 3 mm lock plate; an 8 mm pin drops through the plate into a guide welded on the frame (WWK-DWG-104). Front pins lift out to let the casters swivel; rear pins stay in, R-clipped. New BOM line 16. | One headset and lock set for all four corners; standard bicycle parts that a market mechanic knows (R12). |
| P8 | The hip bar posts filled the sleeves (solid parts overlapping, 187,500 mm³), were 280 mm long (50 mm left in the sleeve at full height), and the 32 mm grip tubes take no standard grip or lever. The push sensor's box sat where the post comes out of the sleeve. | Sleeves are tubes with a 1 mm sliding clearance on 364 mm posts (150 mm in the sleeve at full height) with nine height holes and a 6 mm pin. Grip tubes are 22.2 mm. The sensor mount is a 4 mm tab on the right sleeve, and the sensor sits outboard of it (WWK-DWG-107). | Enough insertion to carry the hip push; standard bicycle grips and brake lever fit 22.2 mm tube. |
| P9 | The drum brake reaction arm stopped in the air 120 mm ahead of the axle. | The reaction arm lies along the outer fork blade and is held by its clip, as drum hubs are fitted to forks. | It must react the brake torque on the fork. |
| P10 | The parking lock pin was held only by one tab on the inner blade, so the spokes bent it as a cantilever: about 213 MPa when parked on 20 %, a factor of 1.1. | A second tab on the outer blade holds the pin's far end (WWK-DWG-105). The pin is a 10 mm ball-lock pin about 140 mm long that ends inside the axle nuts. | Held at both ends the pin sees 119 MPa, a factor of 2.0; nothing projects beyond the axle nuts (R6). |
| P11 | The skirt guards had no fixing, and their round hub hole meant they could not go on with the wheel in place. | Each guard bolts to two tabs on the side rail (5 mm out from the rail) and is held by two rubber-lined clips on the inner fork blade. The hub hole is a 120 mm slot open at the bottom (WWK-DWG-106). | The guard is fitted before the wheel and the hub rises into the slot; it stays 15 mm from the spokes. |
| P12 | The fork blades, 12 mm thick, overlapped the hubs by 3 mm. | Dropouts 6 mm thick at the axle, blades outside the hub's over-locknut width. | Matches a real fork; overall width over the axle nuts stays 898 mm. |
| P13 | The torque-arm tab for the later motor was part of the frame weldment but sat on the bought fork blade. | It is welded to the back of the right rear fork's outer blade by the frame builder, with the lock pin tabs (WWK-DWG-105). | It has to be on the fork the motor sits in. |
| P14 | The cradle walls overlapped at the corners and had no fixings. | End walls fit between the side walls; 14 zinc angle brackets with M4 bolts outside the walls; strap anchors through the side walls (WWK-DWG-108). | 4 mm plywood is too thin for screws in its edge. |
| P15 | Frame members overlapped one another at every joint. | Members butt on each other's faces, so each has a real cut length (WWK-BLD-001, Table 2). | A welder needs a cut list. |
| P16 | The receiver plate lapped 5 mm onto the upper cross member. | It laps 15 mm. | Room for a fillet weld. |

*Table 2. Knock-on changes (WWK-CAL-001 v0.3).*

| Item | Change | Reason |
| --- | --- | --- |
| Mass | Empty 37.4 to 39.6 kg (46.1 kg with the assist kit); loaded 121.8 to 124.0 kg. | Carrier, second rear brackets, rear headsets, lock collars, fixings and brackets added (+2.2 kg). |
| Push force | Firm path 59.7 to 60.8 N (R2 now not met, by 0.8 N); 10 % climb 178.3 to 181.5 N (R4 now not met, by 1.5 N); sand 236 to 358 N to 240 to 365 N. | Follows the mass. See Table 3. |
| Frame | The rail is now carried on the hip sleeve at the rear, and the cradle hangs from the cross members: rail at the rear cross member 102 MPa (factor 2.30), front riser 115 MPa (2.04), caster arm root 129 MPa (1.82). The weld stress range in the rail falls from 75 to 61 MPa, below the 71 MPa reference. | The load path follows the constructable layout. |
| Cost | First prototype $426 to $462: USD 12 over the USD 450 value-engineering target. BOM lines 1, 3, 5, 8, 12 and 15 repriced; line 16 added. | Parts added for construction. |
| Drawings | WWK-DWG-001 Rev P3; making sketches WWK-DWG-101 to 108 added. | Follows the model. |
| Documents | WWK-CAL-001 v0.3, WWK-REQ-001 v0.5, WWK-PRC-001 v0.5, BOM line 16. | Follows the model. |

*Table 3. Decided by Amish, 2026-10-02.*

| # | Question | Options | Recommendation |
| --- | --- | --- | --- |
| A1 | R2 and R4 move from at risk to not met by 0.8 N and 1.5 N, because the constructable carrier is 2.2 kg heavier. | (a) accept on paper and confirm the push limits with users in co-design, as for R9; (b) apply the two mass options left open in WWK-DDR-002 (tires without a puncture belt, no liners: 1.6 kg, which brings R2 to 60.0 N and R4 to 179.2 N, both at risk); (c) lighter bearers and rear brackets in 1.2 mm wall (about 0.5 kg). | (a), keeping puncture protection, which Amish chose to keep on 2026-09-25. **Decided by Amish, 2026-10-02: (a).** |
| A2 | Ground clearance under the cradle carrier is 125 mm, not the 150 mm under the concept's floor. No requirement covers it. | (a) accept; (b) raise the cradle 25 mm (lift height 389 mm, centre of mass 25 mm higher). | (a); add a clearance figure to the requirements after the first route survey. **Decided by Amish, 2026-10-02: (a).** |

## Consequences

- `design_state: constructable` in `project.yaml`. The build plan WWK-BLD-001 shows every component and step in pictures generated from the model (`cad/src/build_plan_media.py`).
- Requirement status (WWK-CAL-001 v0.3): 2 met, 5 at risk, 4 not met (R2, R3, R4, R9), R11 over the value-engineering target by USD 12, R13 not verifiable at TRL 3.
- The photoreal renders (`media/render-*.png`), `media/card.png`, `media/social-preview.png` and the appearance model `cad/src/product_model.py` still show the concept: one rear bracket, rear axles under the head tubes, straight caster arms on stubs, 32 mm grip tubes and no cradle carrier. They need updating on Amish's Mac.
- The fork offset, the headset standard and the drum hub's reaction arm are to be confirmed when parts are bought (WWK-DEC-001).

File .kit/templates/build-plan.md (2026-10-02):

---
doc_id: PRJ-BLD-001
title: Project prototype build plan
project: Project name
doc_type: Build plan
version: "0.1"
status: Draft
date: YYYY-MM-DD
author: Amish Chadha
license: CERN-OHL-S-2.0
revisions:
  - version: "0.1"
    date: YYYY-MM-DD
    author: Amish Chadha
    change: First build plan; design made constructable
---

# Project prototype build plan

**Plan, not yet built.** How to build the first proof-of-concept prototype, component by component. Building and testing to it is TRL 4 work. Decisions still to be made are kept in the design decisions register (`docs/06-design-decisions.md`), not here.

## 1. What you are building

Every component, pulled apart and numbered in build order

One short paragraph: what the prototype is, how many components, which are made and which are bought, and the main ways they are made.

## 2. What changed to make it buildable

| Component | The concept had | The buildable design has | Why |
| --- | --- | --- | --- |

## 3. Making the components

### 3.1 Component name

Making sketch

**What it is and what it is made from.**

**How to make it.**

1. Mark out ...
2. Cut ...

**How it fits the parts next to it.**

Close-up of the joint

**Check before moving on.**

## 4. Putting it together

### Step 1: ...

Step 1

## 5. First checks

| Check | Requirement | How | Pass when |
| --- | --- | --- | --- |

## 6. Safety stops

## 7. Tools, skills and workspace

## 8. Where the numbers come from

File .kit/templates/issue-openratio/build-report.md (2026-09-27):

---
name: Build report
about: Tell us what happened when you built, printed or tested part of this design
title: "Build report: "
labels: build-report
---

This is a research and educational prototype, not a medical device. It is a TRL 3 concept and is not released for fabrication. If you build any part of it, you do so at your own risk. Reports help everyone.

**What you built** (part, sub-assembly or test)

**Materials, tools and settings**

**What worked**

**What did not work, with photos or measurements if you have them**

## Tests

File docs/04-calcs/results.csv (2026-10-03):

key | value | unit_or_note
overall_width | 898 | mm
walk_width | 610 | mm
riser_gap | 19.5 | mm
overall_length | 2197 | mm
jerrycan_spare | 48 | mm
pot_spare | 12 | mm
lift_height | 364 | mm
frame_tube_length | 9.72 | m
mass_empty | 40.28 | kg
mass_empty_assist | 49.63 | kg
mass_loaded | 124.68 | kg
mass_loaded_assist | 134.03 | kg
mass_empty_v03 | 39.57 | kg
mass_empty_v02 | 37.35 | kg
mass_options_total | 1.60 | kg
mass_empty_with_options | 38.68 | kg
x_cg | 712 | mm
z_cg | 365 | mm
crr_sand_lo | 0.197
crr_sand_hi | 0.300
fat_tire_factor | 0.75
F_firm_hi | 61.2 | N
F_sand_lo | 241 | N
F_sand_hi | 367 | N
F_climb_hi | 182.6 | N
F_desc_hi | 97 | N
F_firm_hi_options | 60.4 | N
F_climb_hi_options | 180.2 | N
F_sand_half_hi | 243 | N
F_sand_assist1_hi | 274 | N
thrust_needed_R3 | 244 | N
F_sand_assist2_hi | 154 | N
assist_Wh_per_km_1 | 83 | Wh/km
assist_Wh_per_km_2 | 170 | Wh/km
assist_current_2 | 7.8 | A
assist_range_1 | 5.4 | km
yaw_moment | 46 | N m
F_park_20 | 258 | N
hand_park_20 | 192 | N
mu_req_park | 0.41
hand_stop_10 | 128 | N
hand_hold_10 | 72 | N
dm_spring | 390 | N
dm_squeeze | 98 | N
dm_hold | 24 | N
dm_grade | 12.0 | %
dm_stop | 2.6 | m
rail_stress | 102 | MPa
arm_stress | 129 | MPa
arm_fos | 1.82
arm_fos_15 | 2.22
arm_stress_30sq | 158 | MPa
fatigue_range | 61 | MPa
frame_twist | 2.06 | deg
rut_accommodated | 28 | mm
axle_stress_cantilever | 472 | MPa
axle_stress_fork | 89 | MPa
bracket_stub_stress_park | 97 | MPa
bracket_arm_fos | 4.7
sleeve_fos_park | 1.8
bearer_fos | 2.2
ground_clearance | 125 | mm
pin_fos_both_ends | 1.9
turn_circle_inner | 3.66 | m
turn_circle_spin | 3.41 | m
tip_side | 47 | deg
assist_target | 450.00 | USD
cost_base | 492.00 | USD
cost_assist_kit | 450.00 | USD
req_R1 | at risk | 84.4 kg (jerrycans), 56 kg (pots); spare length 48 mm (cans), 12 mm (pots)
req_R2 | not met | 24 to 61.2 N
req_R3 | not met | 241 to 367 N unassisted; 154 N worst with the two-motor kit
req_R4 | not met | 182.6 N climb; hold-back hand force 72 N; hold-to-release brake holds up to 12 % if let go
req_R5 | met | 3.66 m (inner rear wheel pivot), 3.41 m (spin)
req_R6 | at risk | 898 mm over axle nuts
req_R7 | at risk | 0 mm; 610 mm; 850 to 1050 mm; both rear wheels
req_R8 | met | 364 mm
req_R9 | not met | 40.3 kg (49.6 kg)
req_R10 | at risk | lock pin for parking; hand 192 N at the latch; hold-to-release brake squeeze 98 N, hold 24 N; friction needed up to 0.41
req_R11 | over the target by $42 | $492
req_R12 | at risk | 100 mm drum hubs, 26 in rims, tires, tubes, cables, headsets
req_R13 | not verifiable at TRL 3 | mounting plate, torque-arm tabs on both rear forks, sensor tab in the model; class V1 retention by test only

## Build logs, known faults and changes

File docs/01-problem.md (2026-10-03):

---
doc_id: WWK-PRB-001
title: WaterWalker problem statement
project: WaterWalker
doc_type: Problem statement
version: "0.5"
status: Draft
date: '2026-10-02'
author: Amish Chadha
license: CERN-OHL-S-2.0
revisions:
- version: "0.1"
  date: '2026-09-24'
  author: Amish Chadha
  change: Initial scaffold
- version: "0.2"
  date: '2026-09-24'
  author: Amish Chadha
  change: Populate to TRL 2 (users, context, constraints, prior work, co-design first)
- version: "0.3"
  date: '2026-09-25'
  author: Amish Chadha
  change: TRL 3. Record Amish's decisions (WWK-DDR-001) on the budget scope, the cradle and the co-design partner; add the questions raised by WWK-CAL-001
- version: "0.4"
  date: '2026-09-25'
  author: Amish Chadha
  change: Recommendations accepted by Amish (DDR-002); co-design questions updated for the lighter carrier and the parking lock pin
- version: "0.5"
  date: '2026-10-02'
  author: Amish Chadha
  change: Partner and region answered by Amish's decision of 2026-10-02 (WWK-DEC-001)
---

# WaterWalker problem statement

Women and girls in rural sub-Saharan Africa and other low-income regions walk long distances carrying about 20 L of water on their heads per trip, which limits the quantity collected and causes neck and spine injuries. Design with, not for: requirements must come from co-design sessions and field trials with the intended users through a local partner.

## Co-design comes first

This design is for communities the author is not part of. Every number in this repo is a desk estimate until the women and girls who carry water have shaped it. Co-design is the first piece of work, not a final check, and it can change the concept, including whether a wheeled carrier is wanted at all.

## User research and co-design

This design is for communities the author is not part of, so requirements come from the people who will use it.

- [ ] Identify a local partner organization (Helpful Engineering network, NGO or university)
- [ ] Run co-design sessions with intended users; record who, where and what was learned
- [ ] Validate load, distance, terrain and cost assumptions in the field
- [ ] Revise requirements (REQ) from findings before freezing the design

Partner and region: decided by Amish on 2026-10-02 (WWK-DEC-001). The Helpful Engineering network is the route to a first partner, a university engineering department or water and sanitation NGO in semi-arid eastern Kenya; Kitui County is the first candidate region. None has been approached yet.

Questions to bring to the first sessions:

- Which containers are used: jerrycans, clay pots, buckets or a mix, and how often each?
- Who fetches water, at what times, with whom, and would a shared carrier work for several households?
- What are the paths like: width, sand, slopes, steps, ditches, stream crossings?
- Where would the carrier be stored at night, and who would repair it?
- Is pushing a wheeled carrier socially acceptable for women and girls, and does anything about its look or use carry stigma or risk (for example theft or being taken over by others)?
- What would a household or women's group pay, and would it be bought, shared or rented?
- Added at TRL 3 (WWK-CAL-001): How heavy a carrier can users lift over a step or ditch when empty (the design is about 37 kg)? How long are the sandy stretches on the route, and would users carry two jerrycans there and make two passes? Is the parking lock pin, pushed through the rear spokes, easy to use and remember to pull before moving off (WWK-DDR-002)? Is 37 kg empty acceptable, or must R9 (35 kg) hold? Would users want a brake that applies when they let go (a dead-man brake)?

## The problem

Where there is no piped supply at home, water is carried from a borehole, tap stand, well or river. The load is usually a 20 L jerrycan or clay pot on the head, about 20 kg of water per trip. Carrying this every day places a large compressive load on the neck and spine and is associated with pain and musculoskeletal injury. Because one person can only carry one container, the household's water use is limited by the number of trips, and the time spent walking and queueing falls mostly on women and girls, often at the expense of school, paid work and rest.

A household of five using about 20 L per person per day (a commonly used basic-access figure) needs about 100 L per day, which is five head-carried trips. Wheels can move several containers per trip, but existing rolling carriers struggle in exactly the places where the walk is hardest: loose sand, slopes and narrow, uneven paths.

## Users and context

| User | Need | Context |
| --- | --- | --- |
| Women and girls who fetch water (primary) | Bring home more water in fewer trips with less strain on the neck and back, on the paths they already use | Daily trips of about 1 to 6 km round trip, often more than once a day; walking in long skirts or wraps; sometimes with a child on the back |
| Household | Enough water for drinking, cooking, washing and hygiene | Rural homestead, 4 to 8 people |
| Women's group or community water committee | A carrier that can be shared, kept working and repaired locally | Village or cluster of homesteads |
| Local bicycle mechanic or welder | Parts and repairs they already know how to do | Market town workshop |
| Partner organization | An open design that can be adapted, built and trialled locally | NGO, university or maker network |

## Constraints

- Garage-buildable first prototype, about $450 USD (`project.yaml`). Amish decided on 2026-09-25 that this budget covers the first prototype without assist but with mounting points for it; the assist kit is a later prototype, and a SwapCell pack, if used, is priced once in the SwapCell project (WWK-DDR-001).
- Terrain: dirt footpaths with ruts, roots and stones; loose sand in dry riverbeds and sandy regions; slopes of about 10 % on routes to water points, occasionally steeper for short distances.
- Narrow paths: many footpaths and gates are under 1 m wide, and some are narrower.
- Walking, not riding: no balance or riding skill needed, usable on slopes and in long skirts, and culturally acceptable for women and girls of all ages.
- Containers: must carry the users' own 20 L jerrycans (four per trip), and should accept clay pots, which are heavy and fragile (two per trip, decided 2026-09-25).
- Local repair: wear parts must be standard bicycle parts sold in rural markets, and the frame must be mild steel that a local welder can repair.
- Storage: small enough to keep inside or beside a house at night.
- Optional electric assist must be removable, and the carrier must work fully without it.

## Prior work

- **Head carrying** remains the most common method. It needs no equipment and works on any path, but limits each trip to about 20 L.
- **Hippo Roller.** A rolling drum of about 90 L pushed or pulled with a steel handle. It moves far more water per trip than head carrying and is widely deployed. Reported weaknesses include high effort on sand and uphill, difficulty turning because the drum must be skidded sideways, control on descents, and cost for a single household.
- **Wello WaterWheel.** A rolling container of about 45 L pushed with a handle, designed in India. It shares the rolling-drum approach and, with it, the same limits on sand, slopes and turning.
- **Bicycles loaded with jerrycans.** Common in East Africa: several jerrycans hung on a bicycle that is pushed by hand. It shows that standard bicycle wheels and parts are accepted and repairable locally, but the load sits high and the bicycle is unstable when pushed.
- **Wheelbarrows and hand carts.** Available and familiar, but one-wheeled barrows need lifting and balance, and carts are wide and heavy.
- **Lopifit walking bike.** A Dutch walking bike on which the rider walks on a treadmill between the wheels, with a motor driving the bike. It inspired the walk-inside layout. WaterWalker deliberately has no treadmill: a treadmill needs a motor to be useful and wastes energy on rough ground.
- **Rollators.** Walking frames where the user stands inside a U-frame and pushes. They show that walking inside a wheeled frame is intuitive and needs no training.

## Out of scope

- Water treatment, storage at home and water source development.
- Pedalled or ridden vehicles, and anything that carries people.
- Animal-drawn or motor vehicles for road use.
- Large-scale manufacturing and distribution, which depend on a partner and on co-design results.

## Open questions

- Which partner and which region for the first co-design sessions? Decided by Amish, 2026-10-02 (WWK-DEC-001): through the Helpful Engineering network, with Kitui County, Kenya, as the first candidate region.
- How common are clay pots relative to jerrycans in the first region, and what size are they? The cradle takes two pots of up to about 384 mm diameter (WWK-CAL-001).
- What path width must the carrier fit? Proposed target 0.9 m, awaiting field data.

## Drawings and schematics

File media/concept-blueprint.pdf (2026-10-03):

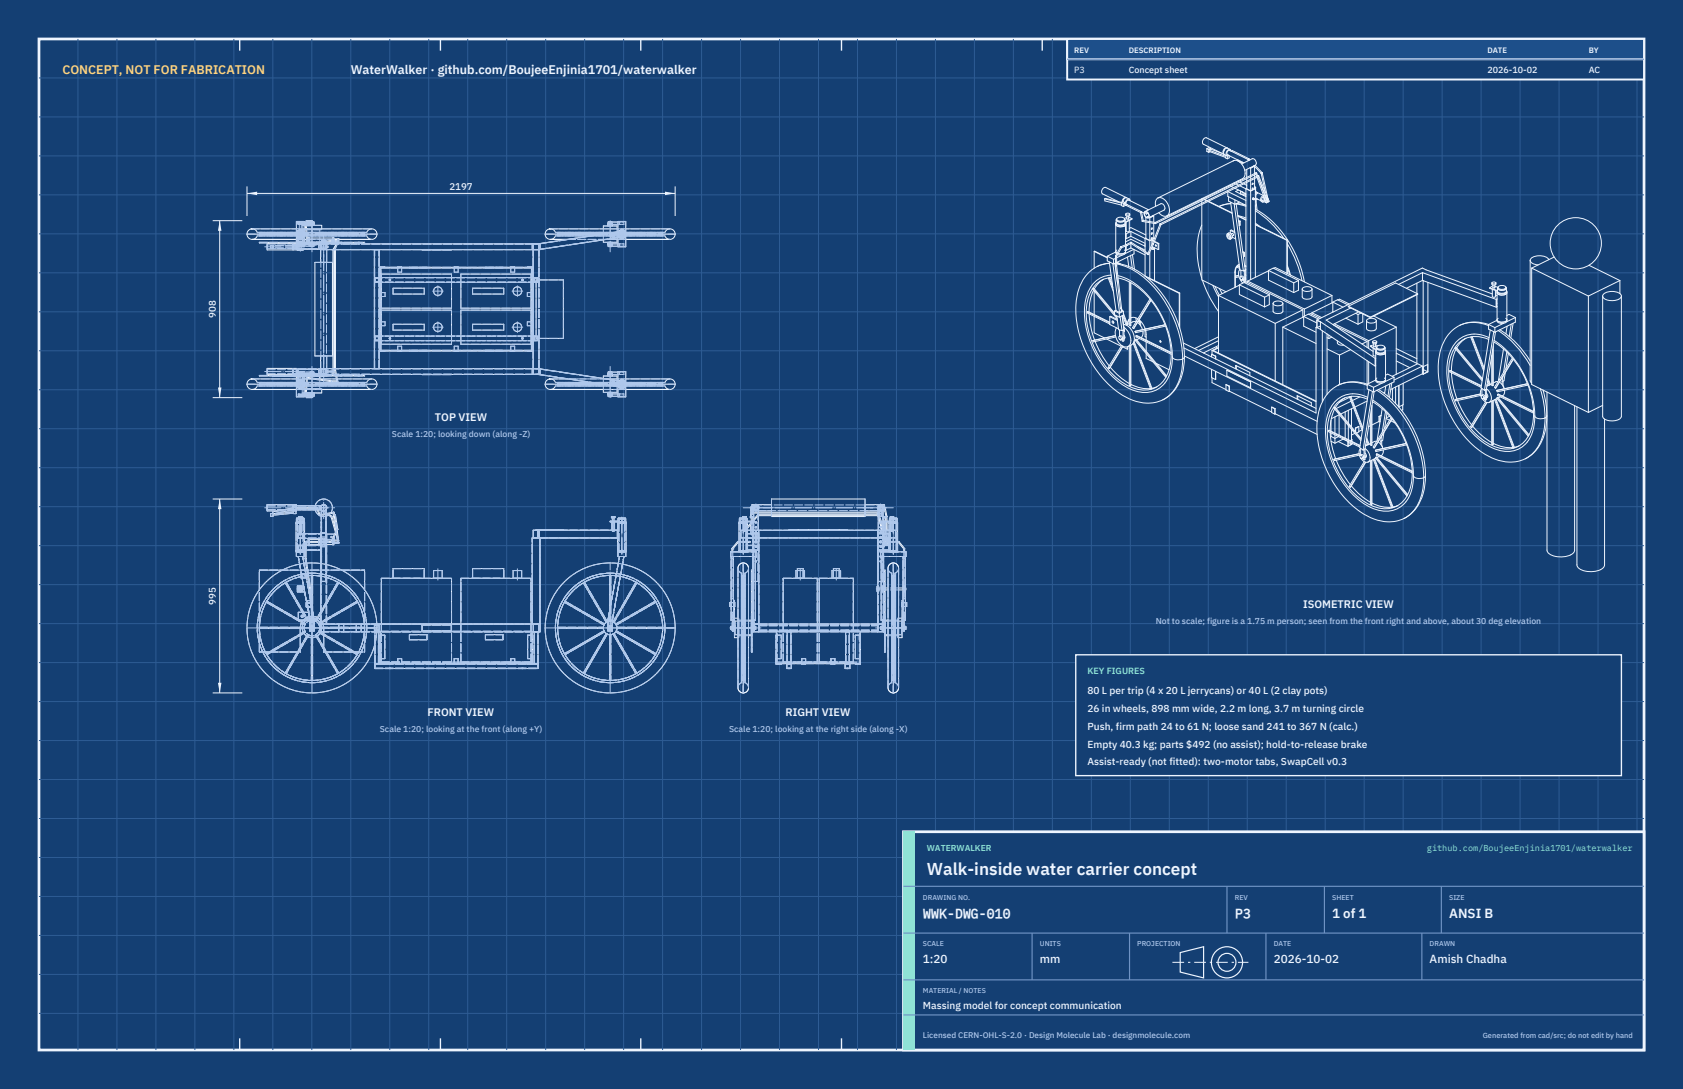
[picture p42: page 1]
CONCEPT, NOT FOR FABRICATION; WaterWalker · github.com/BoujeeEnjinia1701/waterwalker; FRONT VIEW; TOP VIEW; RIGHT VIEW; ISOMETRIC VIEW; REV; DESCRIPTION; DATE; Concept sheet; WATERWALKER; github.com/BoujeeEnjinia1701/waterwalker; DRAWING NO. WWK-DWG-010; REV P3; SHEET 1 of 1; SIZE ANSI B; SCALE 1:20; UNITS mm; PROJECTION; DRAWN Amish Chadha; Licensed CERN-OHL-S-2.0 · Design Molecule Lab · designmolecule.com; Generated from cad/src; do not edit by hand

Scale 1:20; looking down (along -Z)

Not to scale; figure is a 1.75 m person; seen from the front right and above, about 30 deg elevation

KEY FIGURES
80 L per trip (4 x 20 L jerrycans) or 40 L (2 clay pots)
26 in wheels, 898 mm wide, 2.2 m long, 3.7 m turning circle
Push, firm path 24 to 61 N; loose sand 241 to 367 N (calc.)
Empty 40.3 kg; parts $492 (no assist); hold-to-release brake
Assist-ready (not fitted): two-motor tabs, SwapCell v0.3

Scale 1:20; looking at the front (along +Y)

Scale 1:20; looking at the right side (along -X)

Walk-inside water carrier concept

MATERIAL / NOTES
Massing model for concept communication

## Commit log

2026-09-24 Initial scaffold: standard open hardware layout, CERN-OHL-S v2 + MIT licenses
    Claude-Session: https://claude.ai/code/session_01XuhhSU4W6fYhgCfURbrkut
    [bom.csv]
2026-09-25 Adopt portfolio kit v1.3.0: session commands, scale figure, 3D viewer, flow diagrams
    Adds .claude/commands (/populate, /advance-trl3, /rein-in, /refresh-media)
    so every Claude Code session starts from the standard prompts, and extends
    concept media with a 1.75 m scale figure, an interactive glTF viewer and
    system or energy flow diagrams. TRL cap 3 unchanged.
    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
2026-09-25 Kit v1.3.1: renderer fixes from the TremorTrace pilot
    Context scale parts for small objects, cutaway exclusions, and text
    labels in flow diagrams.
    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
2026-09-25 Populate waterwalker to a strong TRL 2 with concept media (batch 2)
    Problem, requirements and precis v0.2, massing model and concept media,
    indicative BOM, docs/REVIEW.md with decisions proposed and awaiting Amish.
    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
    [bom.csv]
2026-09-25 Advance waterwalker to TRL 3 (batch 2)
    Decisions approved by Amish 2026-09-25 recorded in DDR-001. TRL 4 is on hold.
    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
    [bom.csv, results.csv, waterwalker-assembly.step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]
2026-09-26 Accept all recommendations (DDR-002), switch footer to designmolecule.com, add README write-up with new inspiration point
    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
    [bom.csv, results.csv, waterwalker-assembly.step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]
2026-09-27 Product appearance model and photoreal renders
    Adds cad/src/product_model.py (appearance model for renders only, all main
    dimensions from model.py) and Blender renders in media/render-*.png,
    captioned with the project, repository and viewing direction. README leads
    with the product render; trl stays 3.
    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
2026-10-01 Image quality pass: legible exploded views, flow diagrams and drawing sheets
    Kit 1.6.1 image layout: the parts list sits in its own column, number bubbles sit on visible parts and never overlap, small parts get a leader, pictures are cropped to the subject, flow labels keep numbers with their units, and sheet captions and the revision table no longer overprint. Concept images, blueprint and general arrangement sheet regenerated; repo-specific labels moved clear of other text and lines.
2026-10-02 Kit 1.7.0: constructable design, illustrated build plan and design decisions register
    The design is now constructable: every part can be made and fits its neighbours, with each change recorded in a Design for construction decision record (made under Amish's 2026-09-30 instruction; ope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
    FlexHand also credits Dr. Geeti Chadha as a contribut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
    [bom.csv, results.csv, waterwalker-assembly.step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]
2026-10-03 Carry approved follow-ups into the design and redo photoreal renders
    Amish approved the follow-up actions from the open-decision sign-off ("APPROVED CHANGES, COMPLETE THESE", 2026-10-02), the design-for-construction change tables in ten repos, the last wave's open dec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
    [bom.csv, results.csv, waterwalker-assembly.step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]

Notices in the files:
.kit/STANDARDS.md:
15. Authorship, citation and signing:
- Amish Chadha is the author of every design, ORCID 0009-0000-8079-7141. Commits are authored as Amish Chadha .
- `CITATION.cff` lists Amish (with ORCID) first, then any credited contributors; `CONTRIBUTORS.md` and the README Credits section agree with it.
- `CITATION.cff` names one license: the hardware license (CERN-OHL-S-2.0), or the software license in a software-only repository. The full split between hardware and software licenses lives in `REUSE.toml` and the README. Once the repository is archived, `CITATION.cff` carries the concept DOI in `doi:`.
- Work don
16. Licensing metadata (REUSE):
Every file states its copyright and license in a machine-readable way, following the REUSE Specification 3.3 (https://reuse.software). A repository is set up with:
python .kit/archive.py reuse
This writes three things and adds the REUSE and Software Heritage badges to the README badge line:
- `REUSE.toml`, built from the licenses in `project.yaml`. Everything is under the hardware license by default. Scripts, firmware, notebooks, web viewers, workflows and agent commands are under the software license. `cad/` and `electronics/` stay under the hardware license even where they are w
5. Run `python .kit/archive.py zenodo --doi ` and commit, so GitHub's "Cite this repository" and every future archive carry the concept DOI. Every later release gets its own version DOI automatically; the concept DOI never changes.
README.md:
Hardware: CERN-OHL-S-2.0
